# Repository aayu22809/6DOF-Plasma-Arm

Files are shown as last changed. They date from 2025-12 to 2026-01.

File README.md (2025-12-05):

# 6-axis Robotic arm with embedded control using Raspberry Pi 5 and Teensy 4.1 for safe application of Cold Atmospheric Plasma

Cold Atmospheric Plasma (CAP) has been known to accelerate wound healing process and sterilize the wound surface, however safe application requires precise control over the application parameters which is not possible when done manually by a clinician. Thus, there is a need for a robotic system which can precisely deliver CAP on complex wound geometries while guaranteeing patient safety. I prospose the designing, fabrication,and validation of a 6-axis open source arm which is optimized for clinical safety. Designs have been made in fusion360 and the first two axis have been 3D printed using reinforced PLA. High resolution closed-loop NEMA 17 motors along with necessary backlash-control gearboxes for precise control while also eliminating the need for brakes. Software is separated into two sections, the Teensy 4.1 microcontroller handles low-level movement, redundancy checking with the motor's inbuilt encoders, and other necessary processes. The raspberry pi 5 will run MATLAB and LinuxCNC and will manage high-level trajectory motion planning, Jacobin inverse kinematics, and provide a GUI for the system. This system will also manage parameters for plasma application. I believe this low-cost arm provides a foundation for plasma robotics in outpatient plasma therapy and adaptable industrial surface-treatment tasks. Future work would include increasing the robot's rigidity and end-effector work volume as well as looking into computer-vision for wound detection.

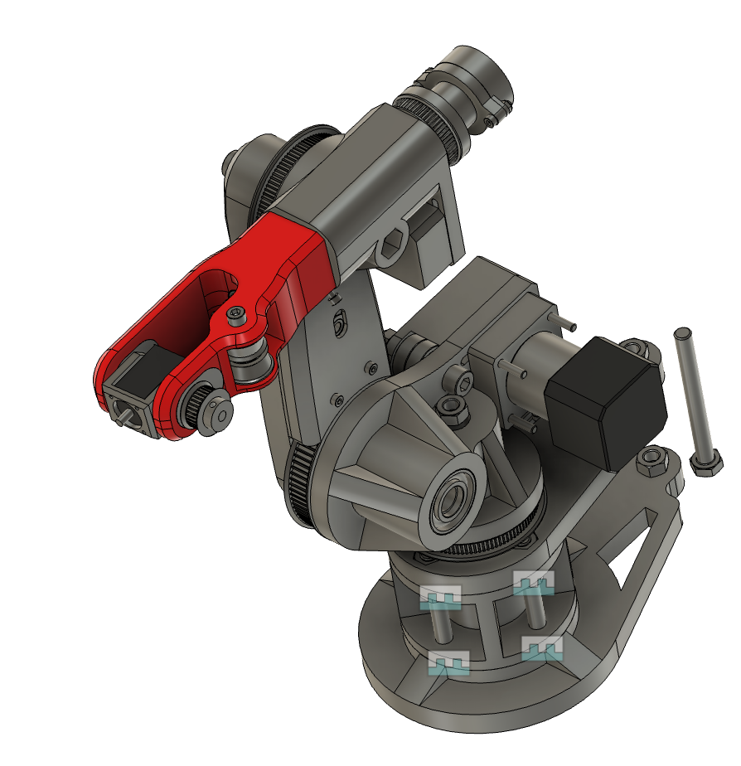
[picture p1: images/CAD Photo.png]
CAD Model


## Features

- **6-Axis Control**: Full 6DOF manipulation capabilities.
- **Closed-Loop System**: Real-time position tracking and error correction using magnetic encoders.
- **Advanced Motion Control**: 
    - Smooth acceleration/deceleration profiles.
    - Synchronized multi-axis movement.
    - Homing and calibration routines.
- **Firmware**:
    - Built for Teensy 4.x / Arduino.
    - **TMC2209 Drivers**: UART control for current setting, microstepping, and diagnostics (StealthChop/SpreadCycle).
    - **Atomic Operations**: Thread-safe variable access for reliable interrupt-based encoder counting.
- **Hardware**: Custom PCB designs for signal routing and driver management.

## Hardware

The project includes custom PCB schematics located in the `pcb schematics` directory. These files include designs for the main controller board and driver interfaces, created in KiCad.

## Firmware Highlights

The core firmware is located in the `test code` directory. The system uses atomic operations to ensure data integrity between high-frequency interrupts and the main loop.

### Atomic Access Macros
Ensures safe reading of volatile encoder data during active motion.
```cpp
#define ATOMIC_BLOCK_START noInterrupts()
#define ATOMIC_BLOCK_END interrupts()

#define ATOMIC_READ(var) ({ \
  ATOMIC_BLOCK_START; \
  auto tmp = var; \
  ATOMIC_BLOCK_END; \
  tmp; \
})
```

### Encoder Verification
The system can self-diagnose direction mismatches between the motor and encoder.
```cpp
// NEW: Verify encoder counts in same direction as motor
void verifyEncoderDirection(uint8_t axis) {
  SERIAL_DEBUG.println("\n=== VERIFYING ENCODER DIRECTION ===");

  enableAxis(axis, true);
  delay(100);

  long startEnc = ATOMIC_READ(axes[axis].encoderCount);

  // Move in positive direction
  digitalWrite(axes[axis].dirPin, HIGH);
  for (int i = 0; i < 800; i++) {  // Quarter revolution
    digitalWrite(axes[axis].stepPin, HIGH);
    delayMicroseconds(STEP_PULSE_WIDTH);
    digitalWrite(axes[axis].stepPin, LOW);
    delayMicroseconds(1000);
  }
  // ... verification logic ...
}
```

## Gallery

### Assembled Arm
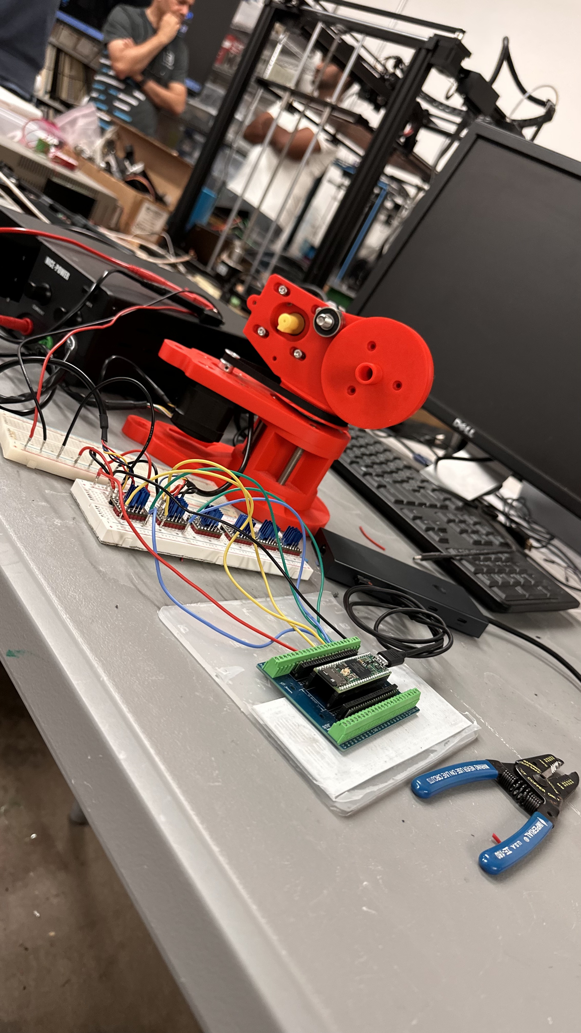
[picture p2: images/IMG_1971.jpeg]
Assembled Arm


### Electronics & Testing
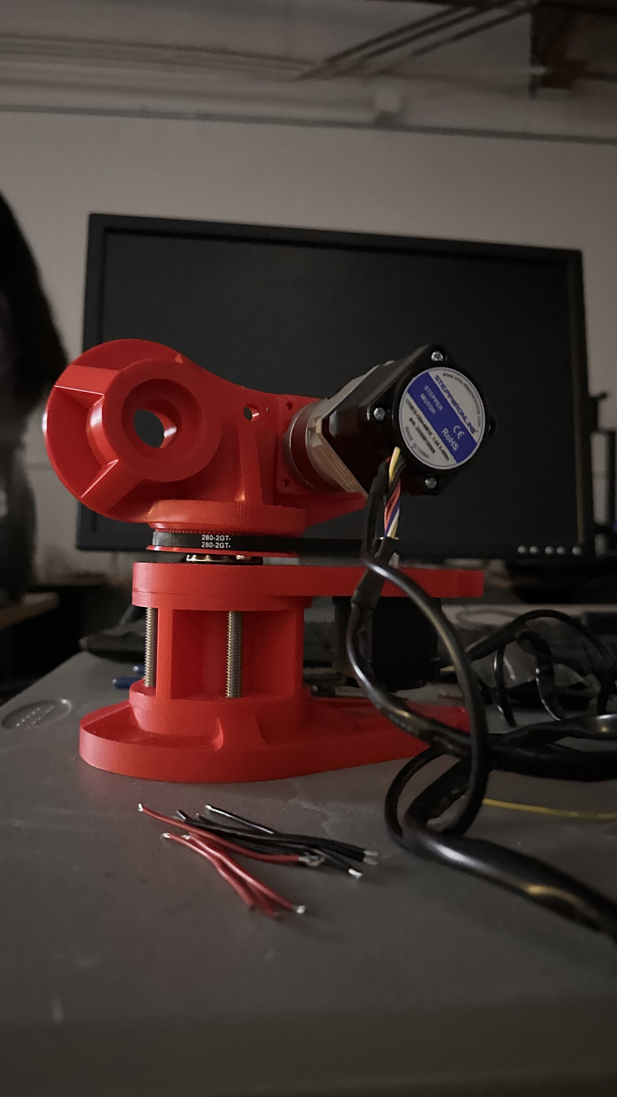
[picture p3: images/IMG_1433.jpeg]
Wiring

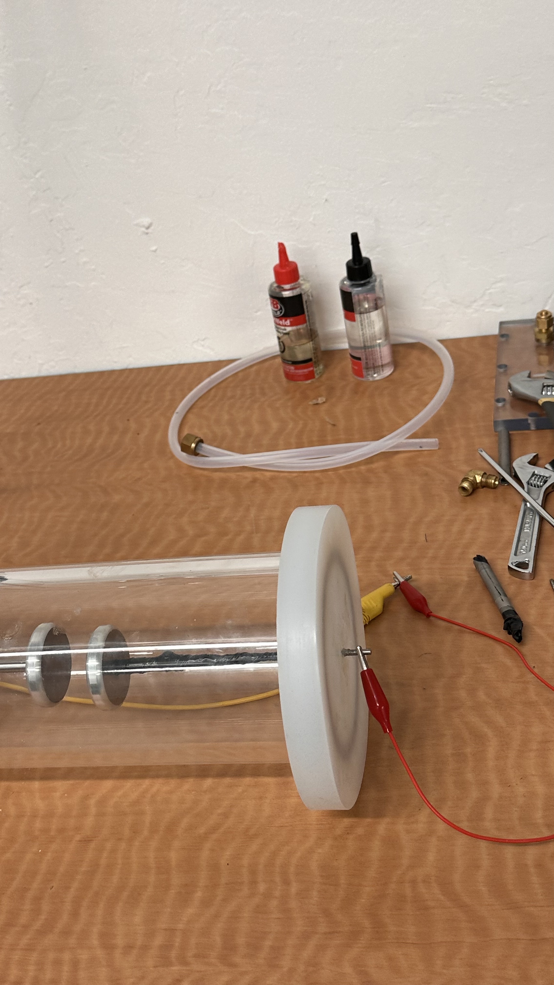
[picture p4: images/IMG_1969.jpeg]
Close up


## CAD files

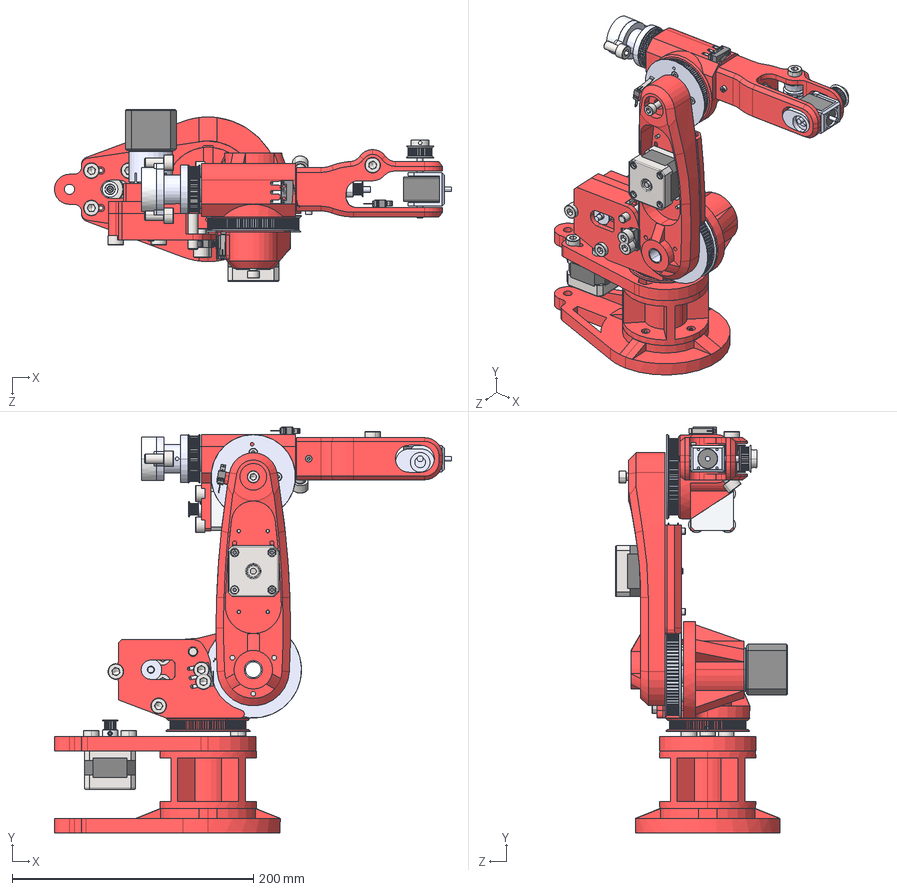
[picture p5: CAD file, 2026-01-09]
STEP files/Assembly step.STEP
329.3 x 336.5 x 142.9 mm
Arm1v2
socket head cap screw_iso_ISO 4762 M8 x 16 - 16N x 31
Base_Predeterminado x 2
Cuerpo_Predeterminado x 2
Tapa_Predeterminado x 2
Eje_Predeterminado x 2
GT2_16T_13x14_____________1 x 4
socket head cap screw_iso_ISO 4762 M6 x 12 - 12N
socket head cap screw_iso_ISO 4762 M3 x 25 - 18N x 4
Toothless pulley 16t gt2 x 2
Arm 2.3
HTD3M 80T
Arm 4.3
HTD80T 2mm spacer
90mm aluputki
Pulley100Tv5
100mm aluputki
Arm2Mountv2
Pulley60Tv2
15mm rikka 1.2mm
Nema 14 stepper
Nema 14 Round stepper
Motor 5 adapter
socket head cap screw_iso_ISO 4762 M4 x 16 - 16N x 4
limit-switch-bottomcase x 4
limit-switch-top-case x 4
pins x 4
switch_lever x 4
6mm akseli
socket head cap screw_iso_ISO 4762 M3 x 16 - 16N x 5
Rotation arm V3
GT2 hihna chamfer rulla x 2
Nema8 Stepperi (banggood.com)
Pulley32TGT2
bearing adapter J6 housing x 2
5mm akseli 2
5mm akseli 1
J6 kotelo
15mm 1.6 rikka
socket head cap screw_iso_ISO 4762 M8 x 40 - 28N
Pulley100TBase
socket head cap screw_iso_ISO 4762 M8 x 50 - 28N
Nema 17 planetary 5 to 1 gearbox
HTD pulley adapter
Motor1 spacer
Basewall cover v2
BaseWall_2_v2
3M HTD 16T 6mm Bore
Bottom spacer
Baseplate
Bottom Tube
Bottom support

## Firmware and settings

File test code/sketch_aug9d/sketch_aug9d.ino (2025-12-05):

/*
 * 6-Axis Robot Controller - FIXED VERSION
 * 
 * Key Improvements:
 * 1. Proper encoder/motor synchronization
 * 2. Atomic access to volatile variables
 * 3. Timer-based stepping (non-blocking)
 * 4. Direction/encoder alignment detection
 * 5. Modular architecture ready for OOP refactor
 */

#include <TMCStepper.h>

// ============================================================================
// ATOMIC ACCESS MACROS
// ============================================================================
#define ATOMIC_BLOCK_START noInterrupts()
#define ATOMIC_BLOCK_END interrupts()

#define ATOMIC_READ(var) ({ \
  ATOMIC_BLOCK_START; \
  auto tmp = var; \
  ATOMIC_BLOCK_END; \
  tmp; \
})

#define ATOMIC_WRITE(var, val) \
  do { \
    ATOMIC_BLOCK_START; \
    var = val; \
    ATOMIC_BLOCK_END; \
  } while (0)

// ============================================================================
// CONFIGURATION
// ============================================================================
#define NUM_AXES 1
#define SERIAL_DEBUG Serial
#define BAUD_RATE 115200

#define MOTOR_STEPS_PER_REV 578    // Correct mechanical step count
#define ENCODER_PPR 1000
#define ENCODER_CPR 4000

#define R_SENSE 0.11f
#define MICROSTEPS 16
#define INTERPOLATION 128
#define DEFAULT_CURRENT 1400
#define STEALTHCHOP_ENABLED true

#define STEP_PULSE_WIDTH 5
#define MIN_STEP_INTERVAL 578   // Faster motion, smoother sound


// ============================================================================
// AXIS STATE STRUCTURE
// ============================================================================
struct AxisConfig {
  // Hardware pins
  uint8_t stepPin, dirPin, enPin;
  uint8_t encAPin, encBPin, encZPin;
  HardwareSerial* serial;
  uint8_t uartAddress;

  // Mechanical config
  float gearRatio;
  uint16_t microstepping;
  uint16_t current_mA;
  bool invertDirection;

  // Motion limits
  float minAngle, maxAngle;
  float maxSpeed;  // deg/sec
  float maxAccel;  // deg/sec²

  // Position tracking (volatile - accessed in ISRs)
  volatile long encoderCount;
  volatile bool indexFound;
  volatile long encoderAtIndex;  // NEW: Encoder value when index triggered

  // Motor state (non-volatile - only accessed in main loop)
  long motorStepTarget;   // Target step position
  long motorStepCurrent;  // Current step position
  bool isHomed;           // NEW: Has axis found home?
  bool enabled;

  // Motion state for timer-based stepping
  volatile bool isMoving;
  volatile long stepsRemaining;
  volatile bool stepDirection;
  unsigned long lastStepMicros;

  // Calibration
  float stepsPerDegree;
  float encoderCountsPerDegree;
  bool directionVerified;       // NEW: Has direction been verified?
  int8_t encoderDirectionSign;  // NEW: +1 or -1 to match encoder to motor
};

// ============================================================================
// PIN DEFINITIONS
// ============================================================================
#define AXIS0_STEP 49
#define AXIS0_DIR 51
#define AXIS0_EN 53
#define AXIS0_ENC_A 18
#define AXIS0_ENC_B 20
#define AXIS0_ENC_Z 2

// ============================================================================
// GLOBALS
// ============================================================================
AxisConfig axes[NUM_AXES];
TMC2209Stepper* drivers[NUM_AXES];
unsigned long lastStatusPrint = 0;

// ============================================================================
// ENCODER ISRs - Optimized Quadrature Decoding
// ============================================================================
void axis0_encoderA_ISR() {
  // Standard quadrature decoding (Gray code)
  static uint8_t lastState = 0;
  uint8_t A = digitalRead(AXIS0_ENC_A);
  uint8_t B = digitalRead(AXIS0_ENC_B);
  uint8_t state = (A << 1) | B;

  // State transition lookup: [lastState][newState] -> direction
  // 0→1→3→2→0 = forward, 0→2→3→1→0 = reverse
  int8_t dir = 0;
  if (lastState == 0b00 && state == 0b01) dir = 1;
  else if (lastState == 0b01 && state == 0b11) dir = 1;
  else if (lastState == 0b11 && state == 0b10) dir = 1;
  else if (lastState == 0b10 && state == 0b00) dir = 1;
  else if (lastState == 0b00 && state == 0b10) dir = -1;
  else if (lastState == 0b10 && state == 0b11) dir = -1;
  else if (lastState == 0b11 && state == 0b01) dir = -1;
  else if (lastState == 0b01 && state == 0b00) dir = -1;

  axes[0].encoderCount += dir * axes[0].encoderDirectionSign;
  lastState = state;
}

void axis0_encoderB_ISR() {
  axis0_encoderA_ISR();  // Same handler, state machine handles both
}

void axis0_encoderZ_ISR() {
  axes[0].indexFound = true;
  axes[0].encoderAtIndex = axes[0].encoderCount;
}

// ============================================================================
// INITIALIZATION
// ============================================================================
void initializeAxisConfigs() {
  // Axis 0
  axes[0].stepPin = AXIS0_STEP;
  axes[0].dirPin = AXIS0_DIR;
  axes[0].enPin = AXIS0_EN;
  axes[0].encAPin = AXIS0_ENC_A;
  axes[0].encBPin = AXIS0_ENC_B;
  axes[0].encZPin = AXIS0_ENC_Z;
  axes[0].serial = &Serial2;
  axes[0].uartAddress = 0x00;

  axes[0].gearRatio = 100.0 / 15.0;  // pulley ratio (output/motor)
  axes[0].microstepping = MICROSTEPS;
  axes[0].current_mA = DEFAULT_CURRENT;
  axes[0].invertDirection = false;

  axes[0].minAngle = -360.0;
  axes[0].maxAngle = 360.0;
  axes[0].maxSpeed = 180.0;
  axes[0].maxAccel = 360.0;

  axes[0].encoderCount = 0;
  axes[0].indexFound = false;
  axes[0].encoderAtIndex = 0;
  axes[0].motorStepTarget = 0;fi
  axes[0].motorStepCurrent = 0;
  axes[0].isHomed = false;
  axes[0].enabled = false;

  axes[0].isMoving = false;
  axes[0].stepsRemaining = 0;
  axes[0].lastStepMicros = 0;

  axes[0].directionVerified = false;
  axes[0].encoderDirectionSign = 1;  // Assume positive initially

  updateAxisCalculations(0);
}

void updateAxisCalculations(uint8_t axis) {
  float motorStepsPerRev = MOTOR_STEPS_PER_REV * axes[axis].microstepping;
  axes[axis].stepsPerDegree = (motorStepsPerRev * axes[axis].gearRatio) / 360.0;
  axes[axis].encoderCountsPerDegree = (ENCODER_CPR * axes[axis].gearRatio) / 360.0;
}

void initializeDrivers() {
  for (uint8_t i = 0; i < NUM_AXES; i++) {
    axes[i].serial->begin(115200);
    drivers[i] = new TMC2209Stepper(axes[i].serial, R_SENSE, axes[i].uartAddress);

    drivers[i]->begin();
    drivers[i]->toff(5);
    drivers[i]->rms_current(axes[i].current_mA);
    drivers[i]->microsteps(axes[i].microstepping);
    drivers[i]->pwm_autoscale(true);
    drivers[i]->en_spreadCycle(!STEALTHCHOP_ENABLED);
    drivers[i]->intpol(true);
    drivers[i]->TPOWERDOWN(128);  // Increased from 20 for better holding

    if (STEALTHCHOP_ENABLED) {
      drivers[i]->TCOOLTHRS(0xFFFFF);
      drivers[i]->semin(5);
      drivers[i]->semax(2);
      drivers[i]->sedn(0b01);
    }

    delay(100);  // Let driver stabilize

    // Verify UART communication
    uint32_t status = drivers[i]->DRV_STATUS();
    SERIAL_DEBUG.print("Driver ");
    SERIAL_DEBUG.print(i);
    SERIAL_DEBUG.print(" DRV_STATUS: 0x");
    SERIAL_DEBUG.println(status, HEX);

    if (status == 0 || status == 0xFFFFFFFF) {
      SERIAL_DEBUG.println("WARNING: UART communication failure!");
    }
  }
}

// ============================================================================
// MOTOR CONTROL - IMPROVED
// ============================================================================
void enableAxis(uint8_t axis, bool enable) {
  digitalWrite(axes[axis].enPin, enable ? LOW : HIGH);
  axes[axis].enabled = enable;
  SERIAL_DEBUG.print("Axis ");
  SERIAL_DEBUG.print(axis);
  SERIAL_DEBUG.println(enable ? " ENABLED" : " DISABLED");
}

// NEW: Verify encoder counts in same direction as motor
void verifyEncoderDirection(uint8_t axis) {
  SERIAL_DEBUG.println("\n=== VERIFYING ENCODER DIRECTION ===");

  enableAxis(axis, true);
  delay(100);

  long startEnc = ATOMIC_READ(axes[axis].encoderCount);

  // Move in positive direction
  digitalWrite(axes[axis].dirPin, HIGH);
  for (int i = 0; i < 800; i++) {  // Quarter revolution
    digitalWrite(axes[axis].stepPin, HIGH);
    delayMicroseconds(STEP_PULSE_WIDTH);
    digitalWrite(axes[axis].stepPin, LOW);
    delayMicroseconds(1000);
  }

  delay(100);
  long endEnc = ATOMIC_READ(axes[axis].encoderCount);
  long encChange = endEnc - startEnc;

  SERIAL_DEBUG.print("Motor DIR=HIGH, Encoder change: ");
  SERIAL_DEBUG.println(encChange);

  if (encChange < 0) {
    SERIAL_DEBUG.println("Encoder counts BACKWARD → Inverting encoder direction");
    axes[axis].encoderDirectionSign = -1;
  } else if (encChange > 0) {
    SERIAL_DEBUG.println("Encoder counts FORWARD → Direction OK");
    axes[axis].encoderDirectionSign = 1;
  } else {
    SERIAL_DEBUG.println("ERROR: No encoder movement detected!");
    return;
  }

  axes[axis].directionVerified = true;
  SERIAL_DEBUG.println("=== DIRECTION VERIFIED ===\n");
}

// NEW: Proper homing sequence
void homeAxis(uint8_t axis) {
  if (!axes[axis].directionVerified) {
    SERIAL_DEBUG.println("ERROR: Run direction verification first!");
    return;
  }

  SERIAL_DEBUG.println("\n=== HOMING SEQUENCE ===");

  enableAxis(axis, true);
  ATOMIC_WRITE(axes[axis].indexFound, false);

  // Rotate to find index pulse
  digitalWrite(axes[axis].dirPin, HIGH);
  while (!ATOMIC_READ(axes[axis].indexFound)) {
    digitalWrite(axes[axis].stepPin, HIGH);
    delayMicroseconds(STEP_PULSE_WIDTH);
    digitalWrite(axes[axis].stepPin, LOW);
    delayMicroseconds(2000);  // Slow homing speed
  }

  delay(100);

  // Synchronize positions
  ATOMIC_WRITE(axes[axis].encoderCount, 0);
  axes[axis].motorStepCurrent = 0;
  axes[axis].motorStepTarget = 0;
  axes[axis].isHomed = true;

  SERIAL_DEBUG.println("Homing complete! Zero position set.");
  SERIAL_DEBUG.println("=== HOMING DONE ===\n");
}

// FIXED: Absolute move with proper position tracking
void moveToAngle(uint8_t axis, float targetAngle) {
  if (!axes[axis].enabled) {
    SERIAL_DEBUG.println("ERROR: Axis not enabled!");
    return;
  }

  if (!axes[axis].isHomed) {
    SERIAL_DEBUG.println("WARNING: Axis not homed! Position may be inaccurate.");
  }

  // Limit check
  if (targetAngle < axes[axis].minAngle || targetAngle > axes[axis].maxAngle) {
    SERIAL_DEBUG.print("ERROR: Angle ");
    SERIAL_DEBUG.print(targetAngle);
    SERIAL_DEBUG.println("° out of range!");
    return;
  }

  // Calculate target in motor steps
  long targetSteps = angleToMotorSteps(axis, targetAngle);
  long currentSteps = axes[axis].motorStepCurrent;
  long deltaSteps = targetSteps - currentSteps;

  SERIAL_DEBUG.print("Moving to ");
  SERIAL_DEBUG.print(targetAngle, 2);
  SERIAL_DEBUG.print("° (");
  SERIAL_DEBUG.print(deltaSteps);
  SERIAL_DEBUG.println(" steps)");

  moveAxisSteps(axis, deltaSteps);
}

void moveByAngle(uint8_t axis, float deltaAngle) {
  // Convert current motor position to angle and add delta
  float currentAngle = motorStepsToAngle(axis, axes[axis].motorStepCurrent);
  moveToAngle(axis, currentAngle + deltaAngle);
}

// IMPROVED: Step execution with proper position tracking
void moveAxisSteps(uint8_t axis, long steps) {
  if (steps == 0) return;

  AxisConfig& a = axes[axis];
  bool direction = steps > 0;
  if (a.invertDirection) direction = !direction;

  digitalWrite(a.dirPin, direction ? HIGH : LOW);
  delayMicroseconds(10); // Direction setup time

  long absSteps = labs(steps);
  a.isMoving = true;

  // --- Compute timing parameters ---
  float maxSpeedStepsPerSec = a.stepsPerDegree * a.maxSpeed;
  float accelStepsPerSec2 = a.stepsPerDegree * a.maxAccel;

  if (maxSpeedStepsPerSec < 10) maxSpeedStepsPerSec = 10; // safety clamp

  // Step timing
  float currentSpeed = 0;
  float targetSpeed = maxSpeedStepsPerSec;
  float stepDelay = 1e6 / 10; // Start slow (10 steps/sec)

  unsigned long lastStepTime = micros();
  long stepsDone = 0;

  // --- Accel-decel control ---
  long accelDistance = (long)((targetSpeed * targetSpeed) / (2.0 * accelStepsPerSec2));
  if (accelDistance > absSteps / 2) accelDistance = absSteps / 2; // triangle profile

  // --- Main stepping loop ---
  while (stepsDone < absSteps) {
    unsigned long now = micros();
    if (now - lastStepTime >= (unsigned long)stepDelay) {
      // Issue one step pulse
      digitalWrite(a.stepPin, HIGH);
      delayMicroseconds(STEP_PULSE_WIDTH);
      digitalWrite(a.stepPin, LOW);

      // Update motor step counter
      a.motorStepCurrent += (direction ? 1 : -1);
      stepsDone++;
      lastStepTime = now;

      // Acceleration phase
      if (stepsDone < accelDistance) {
        currentSpeed = sqrt(2.0 * accelStepsPerSec2 * stepsDone);
        if (currentSpeed > targetSpeed) currentSpeed = targetSpeed;
      }
      // Deceleration phase
      else if (stepsDone > absSteps - accelDistance) {
        long decelStep = absSteps - stepsDone;
        currentSpeed = sqrt(2.0 * accelStepsPerSec2 * decelStep);
        if (currentSpeed < 1) currentSpeed = 1;
      }
      // Cruise
      else {
        currentSpeed = targetSpeed;
      }

      // Compute new delay
      stepDelay = 1e6 / currentSpeed;
      if (stepDelay < MIN_STEP_INTERVAL) stepDelay = MIN_STEP_INTERVAL;
    }
  }

  a.isMoving = false;

  // --- Post-move verification ---
  delay(50);
  long encCount = ATOMIC_READ(a.encoderCount);
  float motorAngle = motorStepsToAngle(axis, a.motorStepCurrent);
  float encoderAngle = encoderCountsToAngle(axis, encCount);
  float error = motorAngle - encoderAngle;

  SERIAL_DEBUG.print("Move complete. Error: ");
  SERIAL_DEBUG.print(error, 3);
  SERIAL_DEBUG.println("°");
}

// ============================================================================
// CONVERSION FUNCTIONS
// ============================================================================
long angleToMotorSteps(uint8_t axis, float angle) {
  return (long)(angle * axes[axis].stepsPerDegree);
}

float motorStepsToAngle(uint8_t axis, long steps) {
  return (float)steps / axes[axis].stepsPerDegree;
}

float encoderCountsToAngle(uint8_t axis, long counts) {
  return (float)counts / axes[axis].encoderCountsPerDegree;
}

// ============================================================================
// DIAGNOSTICS
// ============================================================================
void printAxisStatus(uint8_t axis) {
  long encCount = ATOMIC_READ(axes[axis].encoderCount);

  float motorAngle = motorStepsToAngle(axis, axes[axis].motorStepCurrent);
  float encoderAngle = encoderCountsToAngle(axis, encCount);
  float error = motorAngle - encoderAngle;

  SERIAL_DEBUG.print("Axis ");
  SERIAL_DEBUG.print(axis);
  SERIAL_DEBUG.print(" | Motor: ");
  SERIAL_DEBUG.print(motorAngle, 2);
  SERIAL_DEBUG.print("°");
  SERIAL_DEBUG.print(" | Encoder: ");
  SERIAL_DEBUG.print(encoderAngle, 2);
  SERIAL_DEBUG.print("°");
  SERIAL_DEBUG.print(" | Err: ");
  SERIAL_DEBUG.print(error, 3);
  SERIAL_DEBUG.print("°");
  SERIAL_DEBUG.print(" | Homed: ");
  SERIAL_DEBUG.println(axes[axis].isHomed ? "YES" : "NO");
}

void calibrateAxis(uint8_t axis) {
  if (!axes[axis].isHomed) {
    SERIAL_DEBUG.println("ERROR: Home axis first!");
    return;
  }

  SERIAL_DEBUG.println("\n=== CALIBRATION ===");

  long startEnc = ATOMIC_READ(axes[axis].encoderCount);
  long startSteps = axes[axis].motorStepCurrent;

  moveByAngle(axis, 360.0);
  delay(500);

  long endEnc = ATOMIC_READ(axes[axis].encoderCount);
  long endSteps = axes[axis].motorStepCurrent;

  long encDiff = endEnc - startEnc;
  long stepDiff = endSteps - startSteps;

  float encoderAngle = encoderCountsToAngle(axis, encDiff);
  float motorAngle = motorStepsToAngle(axis, stepDiff);
  float error = ((encoderAngle - 360.0) / 360.0) * 100.0;

  SERIAL_DEBUG.print("Commanded: 360.00°\n");
  SERIAL_DEBUG.print("Motor: ");
  SERIAL_DEBUG.print(motorAngle, 2);
  SERIAL_DEBUG.println("°");
  SERIAL_DEBUG.print("Encoder: ");
  SERIAL_DEBUG.print(encoderAngle, 2);
  SERIAL_DEBUG.println("°");
  SERIAL_DEBUG.print("Error: ");
  SERIAL_DEBUG.print(error, 3);
  SERIAL_DEBUG.println("%");

  if (abs(error) < 1.0) {
    SERIAL_DEBUG.println("✓ CALIBRATION PASSED");
  } else {
    SERIAL_DEBUG.println("✗ CALIBRATION FAILED");
  }

  SERIAL_DEBUG.println("=== CALIBRATION END ===\n");
}

// ============================================================================
// SETUP & LOOP
// ============================================================================
void setup() {
  SERIAL_DEBUG.begin(BAUD_RATE);
  while (!SERIAL_DEBUG && millis() < 3000)
    ;

  SERIAL_DEBUG.println("\n6-Axis Robot Controller v2.0 (FIXED)");
  SERIAL_DEBUG.println("======================================\n");

  initializeAxisConfigs();

  for (uint8_t i = 0; i < NUM_AXES; i++) {
    pinMode(axes[i].stepPin, OUTPUT);
    pinMode(axes[i].dirPin, OUTPUT);
    pinMode(axes[i].enPin, OUTPUT);
    digitalWrite(axes[i].enPin, HIGH);

    pinMode(axes[i].encAPin, INPUT_PULLUP);
    pinMode(axes[i].encBPin, INPUT_PULLUP);
    pinMode(axes[i].encZPin, INPUT_PULLUP);
  }

  attachInterrupt(digitalPinToInterrupt(AXIS0_ENC_A), axis0_encoderA_ISR, CHANGE);
  attachInterrupt(digitalPinToInterrupt(AXIS0_ENC_B), axis0_encoderB_ISR, CHANGE);
  attachInterrupt(digitalPinToInterrupt(AXIS0_ENC_Z), axis0_encoderZ_ISR, RISING);

  delay(100);
  initializeDrivers();

  SERIAL_DEBUG.println("\n=== COMMANDS ===");
  SERIAL_DEBUG.println("SETUP:");
  SERIAL_DEBUG.println("  e - Enable axis");
  SERIAL_DEBUG.println("  d - Disable axis");
  SERIAL_DEBUG.println("  v - Verify encoder direction");
  SERIAL_DEBUG.println("  h - Home to index");
  SERIAL_DEBUG.println("\nMOTION:");
  SERIAL_DEBUG.println("  m[angle] - Move relative (e.g., m45)");
  SERIAL_DEBUG.println("  a[angle] - Move absolute (e.g., a0)");
  SERIAL_DEBUG.println("  + / - - Move ±90°");
  SERIAL_DEBUG.println("\nDIAGNOSTICS:");
  SERIAL_DEBUG.println("  c - Calibrate");
  SERIAL_DEBUG.println("  s - Status");
  SERIAL_DEBUG.println("  r - Reset position");
  SERIAL_DEBUG.println("================\n");

  SERIAL_DEBUG.println("IMPORTANT: Run commands in order:");
  SERIAL_DEBUG.println("1. e (enable)");
  SERIAL_DEBUG.println("2. v (verify direction)");
  SERIAL_DEBUG.println("3. h (home)");
  SERIAL_DEBUG.println("4. Test with m45, a0, etc.\n");
}

void loop() {
  if (SERIAL_DEBUG.available()) {
    char cmd = SERIAL_DEBUG.read();

    switch (cmd) {
      case 'e': enableAxis(0, true); break;
      case 'd': enableAxis(0, false); break;
      case 'v': verifyEncoderDirection(0); break;
      case 'h': homeAxis(0); break;
      case 'c': calibrateAxis(0); break;
      case 's': printAxisStatus(0); break;

      case 'r':
        ATOMIC_WRITE(axes[0].encoderCount, 0);
        axes[0].motorStepCurrent = 0;
        axes[0].isHomed = false;
        SERIAL_DEBUG.println("Position reset (not homed)");
        break;

      case 'm':
        {
          float angle = SERIAL_DEBUG.parseFloat();
          moveByAngle(0, angle);
          break;
        }

      case 'a':
        {
          float angle = SERIAL_DEBUG.parseFloat();
          moveToAngle(0, angle);
          break;
        }

      case '+':
        if (axes[0].enabled) moveByAngle(0, 90.0);
        break;
      case '-':
        if (axes[0].enabled) moveByAngle(0, -90.0);
        break;
    }

    while (SERIAL_DEBUG.available()) SERIAL_DEBUG.read();
  }

  if (millis() - lastStatusPrint > 2000) {
    printAxisStatus(0);
    lastStatusPrint = millis();
  }
}

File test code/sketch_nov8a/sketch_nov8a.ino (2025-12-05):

#include <TMCStepper.h>
#include <AccelStepper.h>
#include <Encoder.h>
#include <TeensyTimerTool.h>
using namespace TeensyTimerTool;

// ========== CONFIGURATION ==========
#define MAX_AXIS 6

// Example for 2 axes now (expand later)
#define NUM_AXIS 2  

// Motor current and UART settings
#define R_SENSE 0.11f  // Sense resistor on your TMC board
#define DRIVER_ADDR 0b00 // Default TMC2209 address (set differently if needed)

// Teensy pins for STEP/DIR per axis
// const uint8_t stepPins[MAX_AXIS] = {2, 4, 8, 11, 18, 25};
// const uint8_t dirPins[MAX_AXIS]  = {26, 28, 9, 12, 19, 26};
const uint8_t stepPins[MAX_AXIS] = {2, 4};
const uint8_t dirPins[MAX_AXIS]  = {26, 28};

// UART Serial ports (only if using UART mode)
HardwareSerial *driverSerials[MAX_AXIS] = {&Serial1, &Serial2, &Serial3, &Serial4, &Serial5, &Serial6};

// Encoder pins (only for closed-loop axes)
const uint8_t encA[MAX_AXIS] = {22, 23, 0, 0, 0, 0};
const uint8_t encB[MAX_AXIS] = {24, 25, 0, 0, 0, 0};
bool isClosedLoop[MAX_AXIS]  = {true, true, false, false, false, false};

// ========== GLOBALS ==========
TMC2209Stepper *drivers[MAX_AXIS];
AccelStepper *steppers[MAX_AXIS];
Encoder *encoders[MAX_AXIS];
PeriodicTimer updateTimer;

// ========== PID SETTINGS (for closed-loop axes) ==========
float Kp = 0.5, Ki = 0.0, Kd = 0.0;
long encoderTarget[MAX_AXIS] = {0};
long encoderError[MAX_AXIS]  = {0};

// ========== FUNCTIONS ==========

// Closed-loop update function (runs every 2ms)
void updateLoop() {
  for (int i = 0; i < NUM_AXIS; i++) {
    if (isClosedLoop[i]) {
      long pos = encoders[i]->read();
      encoderError[i] = encoderTarget[i] - pos;
      float correction = Kp * encoderError[i];  // Minimal PID (P only)
      steppers[i]->moveTo(encoderTarget[i] + correction);
    }
    steppers[i]->run();
  }
}

// ========== SETUP ==========
void setup() {
  Serial.begin(115200);
  delay(1000);
  Serial.println("Teensy Multi-Axis Robot Init");

  for (int i = 0; i < NUM_AXIS; i++) {
    // --- DRIVER SETUP ---
    driverSerials[i]->begin(115200);
    drivers[i] = new TMC2209Stepper(driverSerials[i], R_SENSE, DRIVER_ADDR);
    drivers[i]->begin();
    drivers[i]->rms_current(1200);      // Set motor current (mA)
    drivers[i]->microsteps(16);         // Smooth stepping
    drivers[i]->en_spreadCycle(false);  // Enable stealthChop for silence
    drivers[i]->pwm_autoscale(true);    // Auto PWM scaling

    // --- STEPPER SETUP ---
    steppers[i] = new AccelStepper(AccelStepper::DRIVER, stepPins[i], dirPins[i]);
    // steppers[i]->setMaxSpeed(4000);    // Adjust based on mechanics
    // steppers[i]->setAcceleration(8000);
    if (i == 1) {
      steppers[i]->setMaxSpeed(4000*30);    // Adjust based on mechanics
      steppers[i]->setAcceleration(8000*30);
    } else {
      steppers[i]->setMaxSpeed(4000);    // Adjust based on mechanics
      steppers[i]->setAcceleration(8000);
    }

    // --- ENCODER SETUP ---
    if (isClosedLoop[i]) {
      encoders[i] = new Encoder(encA[i], encB[i]);
      encoderTarget[i] = 0;
    }
  }

  // 500 Hz update loop (2ms)
  updateTimer.begin(updateLoop, 2000);
}

// ========== LOOP ==========
void loop() {
  // Example: simple motion pattern
  static uint32_t t = millis();
  if (millis() - t > 3000) {
    t = millis();
    for (int i = 0; i < NUM_AXIS; i++) {
      long newTarget = random(-5000, 5000);
      steppers[i]->moveTo(newTarget);
      if (isClosedLoop[i]) encoderTarget[i] = newTarget;
      Serial.printf("Axis %d -> Target %ld\n", i, newTarget);
    }
  }
}

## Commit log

2025-12-05 Initial Data Commit
    [6-axis robot.kicad_pcb, 6-axis robot.kicad_sch]
2026-01-09 Add design cad files
    [Assembly step.STEP]
